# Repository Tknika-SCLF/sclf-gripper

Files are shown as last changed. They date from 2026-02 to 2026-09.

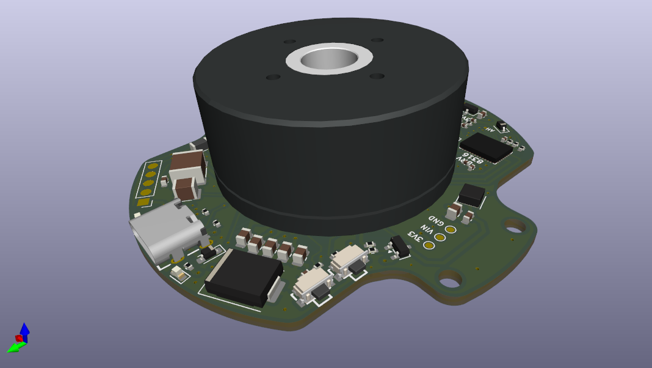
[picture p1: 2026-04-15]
images/Gripper_Motor1.png

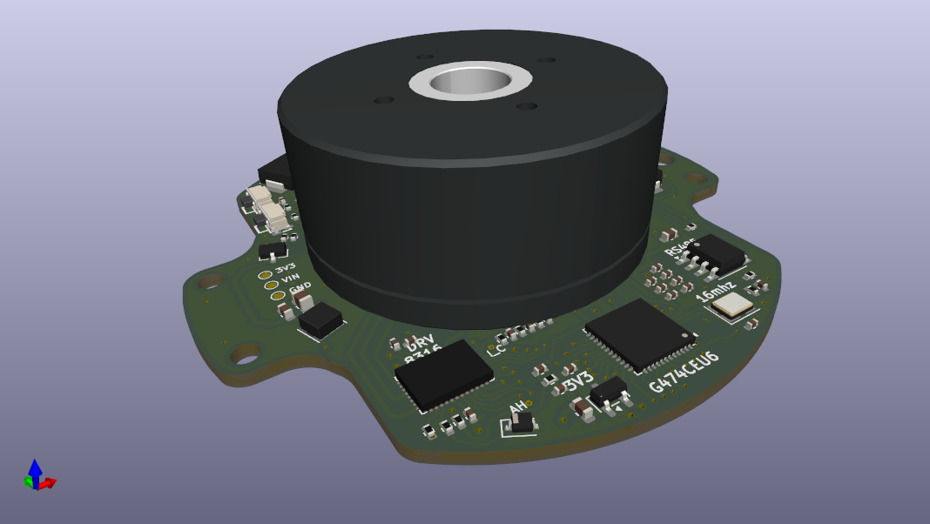
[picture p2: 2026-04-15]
images/Gripper_Motor4.png

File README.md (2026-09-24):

# SCLF Gripper — Firmwarea

[ Euskara ](README.md) | [ English ](README.en.md) | [ Español ](README.es.md)

> Tknikaren SCLF Gripper-erako motor kontrolagailuaren firmwarea.
> STM32G474CEU6 · SimpleFOC · PlatformIO · Antigravity IDE
> Lizentzia: CC BY-SA 4.0

---

> ⚠️ **GARRANTZITSUA:** Proiektu honekin lanean hasi aurretik, mesedez irakurri beti `TASKS.md` fitxategia. Bertan aurkituko duzu proiektuaren uneko egoera zehatza eta garatzaileen arteko hurrengo urratsak zeintzuk diren.

## Hasiera Azkarra

Ingurunea konfiguratuta baduzu dagoeneko:

```bash
# 1. Konpilatu
pio run

# 2. Flasheatu (ST-Link konektatuta)
pio run --target upload

# 3. Serie-monitorea (Gripper-aren USB-C PC-ra)
pio device monitor --baud 115200
```

---

## Ingurunearen Konfigurazioa Hutsetik

### 1. Urratsa — Antigravity Instalatu

Deskargatu eta instalatu Antigravity bere webgune ofizialetik. VSCode/Windsurf-en fork bat da eta modu berean funtzionatzen du.

---

### 2. Urratsa — C/C++ Tools Instalatu

> ⚠️ PlatformIO **ez dago Open VSX-en** (Antigravity-ren marketplace-a). Bi hedapenak eskuz instalatu behar dira `.vsix` fitxategietatik.

**2a.** Joan hona: https://github.com/microsoft/vscode-cpptools/releases/latest

Deskargatu zure sistema eragileari dagokion fitxategia:

| Sistema | Deskargatu beharreko fitxategia |
|---|---|
| Windows (64-bit) | `cpptools-windows-x64.vsix` |
| macOS (Apple Silicon) | `cpptools-macOS-arm64.vsix` |
| macOS (Intel) | `cpptools-macOS-x64.vsix` |
| Linux (64-bit) | `cpptools-linux-x64.vsix` |

**2b.** Antigravity-n: `Hedapenak / Extensions (Ctrl+Shift+X)` → `···` ikonoa (hiru puntu) → **Install from VSIX** → hautatu deskargatutako `.vsix` fitxategia.

---

### 3. Urratsa — PlatformIO Instalatu

**3a.** Joan hona: https://github.com/platformio/platformio-vscode-ide/releases/latest

Ireki azken bertsioaren **"Assets"** atala eta deskargatu fitxategia (adibidez: `platformio-ide-3.3.3.vsix`).

**3b.** Antigravity-n: `Hedapenak / Extensions (Ctrl+Shift+X)` → `···` → **Install from VSIX** → hautatu deskargatutako `.vsix` fitxategia.

**3c.** Berrabiarazi Antigravity. PlatformIOk bere mendekotasunak automatikoki instalatuko ditu lehenengo aldian (2-5 minutu har ditzake).

> ⚠️ **Ohar garrantzitsua:** PlatformIOren instalazioa Antigravity-n ez dago ofizialki onartuta. Konpilazio edo igoera (upload) arazoak badituzu, kontsultatu [Arazoen Konponbidea](#arazoen-konponbidea) atala dokumentu honen amaieran.

---

### 4. Urratsa — cortex-debug Instalatu (ST-Link-ekin debug egiteko)

> 💡 **Zer da Open VSX?** Kode irekiko luzapenen erregistro alternatiboa da (Eclipse Foundation-ek kudeatua). Antigravity-k eta VSCodium-ek ofizialki erabiltzen duten biltegia da, Microsoft-en murrizketak ekiditeko, eta segurua da.

**4a.** Joan hona: https://open-vsx.org/extension/marus25/cortex-debug

Eskuin aldean dagoen **"Version"** goitibeherako menuan, hautatu **"Pre-release"** jartzen EZ duen azken bertsio egonkorra (adibidez: `1.12.1`). Ondoren, sakatu azpian agertzen den **`DOWNLOAD`** botoi morean `.vsix` fitxategia eskuratzeko.

**4b.** Instalatu aurrekoak bezala (Install from VSIX).

**4c.** OpenOCD konfiguratzea:
> 💡 **Albiste ona:** Ez duzu ezer deskargatu edo instalatu behar! PlatformIO-k automatikoki deskargatzen du OpenOCD lehenengo aldiz proiektua konpilatzen edo plakan kargatzen duzunean. Bere kokapena hau izaten da Windows-en:
`C:\Users\ZURE_ERABILTZAILEA\.platformio\packages\tool-openocd\bin\openocd.exe`

*(Cortex-Debug-ek errorea ematen badu OpenOCD ez duela aurkitzen esanez, joan Antigravity-ren ezarpenetara eta ezarri ibilbide hori `cortex-debug.openocdPath` aukeran).*

---

### 5. Urratsa — Git Instalatu

Proiektua klonatzeko Git instalatuta izan behar duzu.

**5a.** Joan hona: https://git-scm.com/downloads

**5b.** Deskargatu eta instalatu zure sistema eragilearen bertsioa (lehenetsitako aukerak mantendu ditzakezu instalazioan).

---

### 6. Urratsa — Proiektua Ireki

```bash
# Klonatu edo kopiatu firmwarearen karpeta
# Ireki Antigravity erro karpetan (platformio.ini dagoen lekuan)
```

Antigravity-n: `File → Open Folder` → hautatu `SCLF_Gripper_firmware/` karpeta.

PlatformIOk automatikoki detektatuko du `platformio.ini` eta honako hauek deskargatuko ditu:
- Platform `ststm32`
- Framework `framework-arduinoststm32`
- Toolchain `toolchain-gccarmnoneeabi`
- `SimpleFOC` liburutegia

---

### 7. Urratsa — Lehenengo Konpilazioa

Antigravity-ren beheko barran, egin klik PlatformIOren ✓ (Build) ikonoan, edo terminaletik:

```bash
pio run
```

**Espero den emaitza:**
```
[SUCCESS] Took X.XX seconds
RAM:   [=         ]  X.X% (used XXXX bytes from 131072 bytes)
Flash: [=         ]  X.X% (used XXXXX bytes from 524288 bytes)
```

Konpilatzen ez badu → ikusi [Arazoen Konponbidea](#arazoen-konponbidea).

---

### 8. Urratsa — ST-Link Konektatu eta Flasheatu

Konektatu ST-Link SCLF Gripper-aren SWD atakara:

| Pin ST-Link | Pad Gripper | Seinalea |
|---|---|---|
| SWDIO | DIO | PA13 |
| SWCLK | CLK | PA14 |
| RST | RST | PG10 |
| GND | GND | — |
| 3.3V | 3V3 | (STM32 soilik elikatzen du, ez encoderra ez driverra) |

> ⚠️ **Elikadura:**
> - ST-Link-aren 3.3V pina **nahikoa da** STM32 flasheatzeko eta encoderra (MT6701) elikatzeko. Bera bakarrik probatu dezakezu 24V konektatu gabe.
> - **BAINA** DRV8316 driverrak eta motorrak **24V kanpokoa** behar dute. Test osoetarako (motorra mugitu), beti konektatu 24V elikadura.

Flasheatu:
```bash
pio run --target upload
```

**Espero den emaitza:** `[SUCCESS]` eta D4 LEDa (PC6) keinuka hasiko da.

#### Aurre-test gomendatua: LED Heartbeat

Test konplexuak egin aurretik, egiaztatu STM32 abiarazten dela:

1. Aldatu `build_src_filter` `platformio.ini`-n:
   ```ini
   build_src_filter = +<../examples/fase0_led_heartbeat>
   ```
2. Flasheatu `pio run --target upload` erabiliz.
3. D4 LEDak 5Hz-ra keinuka egin behar du (200ms). Keinurik ez bada → elikadura edo ST-Link kableatu arazoa.
4. Berreskuratu jatorrizko `build_src_filter` Fase 1.1-era itzuli nahi duzunean.

---

### 9. Urratsa — Encoderra Egiaztatu (Fase 1.1)

> ⚠️ **Baldintzak:** ST-Link-aren 3.3V konektatuta izatea nahikoa da encoderra elikatzeko. Ez da 24V behar fase honetarako.

`fase1_1_mt6701_test`-eko firmware-ak D4 LEDa diagnostiko bisual modura erabiltzen du (Serial gabe):

1. Egiaztatu `build_src_filter` horrela dagoela `platformio.ini`-n:
   ```ini
   build_src_filter = +<../examples/fase1_1_mt6701_test> +<encoder/>
   ```
2. Flasheatu: `pio run --target upload`
3. Begiratu D4 LEDa:

| LED portaera | Esanahia |
|---|---|
| 3 keinu azkar abiaraztean | `setup()` ondo amaituta |
| LED motela (700ms, ~0.7Hz) | Motorra lehen erdibiraketan (0°-180°) |
| LED azkarra (80ms, ~6Hz) | Motorra bigarren erdibiraketan (180°-360°) |
| **Motorra biratzean aldatzen da** ✅ | **MT6701 encoderrak funtzionatzen du!** |
| Beti azkar aldaketarik gabe | SPI-k 0xFFFF bueltatzen du → encoderrak elikadurarik ez |

✅ **LEDak motorra biratzean aldatzen badu, Fase 1.1 gaindituta dago.**

### 9b. Urratsa — Serial Monitor Egiaztatu (USB VCP)

> ✅ **EGOERA:** Ondo funtzionatzen du. Firmwareak `SystemClock_Config` bloke bat dauka `main.cpp`-n STM32G4-ren USB periferikorako behar den HSI48 osziladorea gaitzeko.

1. Konektatu USB-C kable bat Gripperraren eta PCaren artean.
2. Ireki PlatformIOren serie-monitorea (🔌 ikonoa beheko barran) edo sartu:
   ```bash
   pio device monitor --baud 115200
   ```
3. Testaren irteera ikusi beharko zenuke pantailan (Adib. `MT6701 Raw (con o sin 24V): X` edo biratzean aldatzen den balio bat).

---

### 10. Urratsa — Faseen Probak eta Adibideak (`examples/`)

Proiektu honen firmware garapena fase ezberdinetan banatuta dago (ikusi `TASKS.md`). Fase bakoitzean idatzitako kode-probak (test standalone-ak) **`examples/`** karpetaren barruan gordetzen dira.

Hardware berria muntatzen baduzu edo sentsore zehatz bat probatu nahi baduzu:
1. Sartu `examples/` karpetan eta aukeratu fasea (adib. `phase1_1_mt6701_test`, `phase1_2_drv_spi`, `phase1_4_rs485_ping`, `phase3_2_rs485_control` edo `phase3_3_ur_rs485`).
2. **Irakurri karpeta horretan dagoen `README.md` fitxategia** argibide zehatzak ikusteko.
   - **Oharra (Phase 3.3):** RS485 komunikazioa 115200 baud-etan doa UR robot eta URCap/URSim integrazio probarako.
3. Kopiatu bertako `main.cpp` fitxategia eta ordezkatu zure probako `src/main.cpp` fitxategiarekin (edo erabili dagokion ingurunea `platformio.ini`-n). 
4. Konpilatu eta igo (`pio run --target upload`).

---

### 11. Urratsa — IA Agentea Konfiguratu

Antigravity-n barneratuta dagoen IA laguntzailearekin lan egiteko:

1. Ireki agentearen txat-panela (IA ikonoa alboko barran).
2. Saio bakoitzaren hasieran, idatzi:

```
Irakurri testuinguru-fitxategi hauek lagundu aurretik:
- AGENT.md   (hardwarea, pinak, arkitektura)
- MEMORY.md  (uneko egoera, kalibratutako parametroak)
- TASKS.md   (orain lantzen ari naizen zeregina)
- RULES.md   (sortutako kodeak errespetatu behar dituen arauak)
```

3. Gero, deskribatu zein zeregin landu nahi duzun `TASKS.md`-tik.

---

## Proiektuaren Egitura

```
SCLF_Gripper_firmware/
│
├── src/
│   ├── main.cpp                    ← Sarrera puntua. 0 FASEA: smoke test
│   ├── config/
│   │   └── pins.h                  ← Pin GUZTIAK. Eskematikoarekin egiaztatuta.
│   ├── encoder/
│   │   ├── MT6701.h                ← Encoder-aren APIa (eskeletoa prest)
│   │   └── MT6701.cpp              ← 1.1 FASEAN inplementatu
│   ├── motor/
│   │   ├── DRV8316.h               ← Gate driver-aren APIa (eskeletoa prest)
│   │   └── DRV8316.cpp             ← 1.2 FASEAN inplementatu
│   ├── comms/
│   │   ├── RS485.h                 ← RS-485 APIa
│   │   └── RS485.cpp               ← RS-485 inplementazioa
│   └── faults/
│       ├── FaultManager.h          ← Akats kudeatzailearen APIa (eskeletoa prest)
│       └── FaultManager.cpp        ← 6 FASEAN inplementatu
│
├── lib/                            ← Bertako liburutegiak
├── test/                           ← PlatformIO Unity testak (8 FASEA)
│
├── examples/
│   ├── phase0_led_heartbeat/        ← 0 Fasea: LED keinua menpekotasunik gabe
│   ├── phase1_1_mt6701_test/        ← 1.1 Fasea: MT6701 encoder proba SPI bidez
│   ├── phase1_2_drv_spi/            ← 1.2 Fasea: DRV8316 SPI komunikazio proba
│   ├── phase1_3_open_loop_v_control/← 1.3 Fasea: Begizta irekiko tentsio kontrola
│   ├── phase1_4_rs485_ping/         ← 1.4 Fasea: RS-485 PING/PONG oinarrizkoa
│   ├── phase2_1_foc_open_loop/      ← 2.1 Fasea: FOC begizta irekiko kontrola
│   ├── phase2_2_foc_closed_loop/    ← 2.2 Fasea: FOC begizta itxia
│   ├── phase3_1_rs485_basic/        ← 3.1 Fasea: RS-485 oinarrizko protokoloa
│   ├── phase3_2_rs485_control/      ← 3.2 Fasea: RS-485 kontrol komando osoak
│   └── phase3_3_ur_rs485/           ← 3.3 Fasea: UR Robot / URCap RS-485 integrazioa
│
├── .vscode/
│   ├── settings.json               ← IDE konfigurazioa (IntelliSense, formatua)
│   ├── extensions.json             ← Gomendatutako hedapenak
│   └── launch.json                 ← Debug ST-Link cortex-debug-ekin
│
├── platformio.ini                  ← Build eta upload konfigurazioa
├── .clang-format                   ← Kode estiloa (gordetzean aplikatzen da)
├── .gitignore
│
├── AGENT.md    ← 📋 IA agentearentzako testuingurua
├── MEMORY.md   ← 🧠 Proiektuaren egoera iraunkorra
├── TASKS.md    ← ✅ Backlog osoa faseka
├── RULES.md    ← 📏 Proiektuaren arauak
└── SRS.md      ← 📄 Eskakizunen zehaztapena
```

### Arkitektura Modularraren Azalpena

Proiektu hau berezibila eta antolatua izateko garatu da:
* **`main.cpp` ("Zuzendaria"):** FOC kontrol-begizta eta hasierako konfigurazioa soilik ditu. Ez da kode nahaspilatuz betetzen.
* **`.cpp` espezifikoak ("Musikariak"):** Txip bakoitzak bere artxibo dedikatua dauka bere funtzio jakingarriagoetarako (adibidez `MT6701.cpp` posizioa zuzenean irakurtzeko erroreak kontrolatuz, edo `DRV8316.cpp` tenperatura edo zirkuitulabur kasuez informatzeko).
* **Modu honetan:** `main.cpp`-ak oinarrizko aginduak ematen ditu, eta modulu bakoitzak badaki bere tresna zehazki nola erabili, etorkizuneko hardware aldaketak izugarri erraztuz.

### Hardware Segurtasuna eta Garapena (⚠️ OSO GARRANTZITSUA)

Antigravity barruan proiektu hau garatzean, [Arau Zorrotzak (RULES.md)](RULES.md) ezarrita daude:
1. **Debekatuta dago Blokeatzea:** Inoiz ez erabili `delay()`, `HAL_Delay` edo `while()` begizta infiniturik FOC exekuzioan. SimpleFOC-ek mikroren %100 erabiltzea eskatzen du korrontea denbora errealean kalkulatzeko. Mikroa "lotaratzeak" motorra edo driverra segundo batean erretzea ekar dezake.
2. **`foc-hardware-setup` Tresna (Skill):** Kodea garatzen hasi aurretik, gure IA laguntzaileak badu tresna espezifiko bat KiCad-eko eskema elektrikoak zuzenean irakurtzeko (`.kicad_sch`) eta `pins.h` fitxategi ezin hobea sortzeko, inolako giza-akatsik gabe. Zure laguna da, erabili proiektuaren azken pinen zehaztapenak egiaztatzeko!
3. **Cortex-Debug Magia:** ST-Link v2 klonarekin edo jatorrizkoarekin, Plaka zuzenean kontrolatu eta pausatu daiteke. Programan aldagairen batek zergatik hartzen duen balio jakin bat deskubritu nahi bada, jarri Breakpoint (eten-puntu) bat Antigravity-n, eta kodea zuzen-zuzenean pausatuko da STM32-an!

---

## PlatformIO Komando Erabilienak

```bash
pio run                          # Konpilatu
pio run --target upload          # Konpilatu eta flasheatu (ST-Link)
pio run --target upload_dfu      # USB DFU bidez flasheatu (BOOT + RST)
pio device monitor               # Serie-monitorea (USB VCP, 115200 baud)
pio test                         # Test unitarioak exekutatu
pio run --target clean           # Konpilazio-artefaktuak garbitu
pio lib install "Simple FOC"     # Eskuz instalatu liburutegia
pio pkg update                   # Plataforma eta liburutegiak eguneratu
```

---

## DFU Bootloader (Flasheatu ST-Link gabe)

ST-Link erabilgarririk ez baduzu, USB DFU bidez flashea dezakezu:

1. Mantendu sakatuta **BOOT** (PB8) botoia.
2. Sakatu eta askatu **RESET** (PG10) botoia.
3. Askatu **BOOT**.
4. Gripperra DFU gailu gisa agertuko da PCan.
5. Aldatu `upload_protocol = dfu` fitxategian `platformio.ini`.
6. Exekutatu `pio run --target upload`.

> 💡 **Oharra ST-Link gabe DFU erabiltzearen inguruan (PA9 pina):**
> Ohiko STM32etan (F1/F4), USB kablea konektatuta dagoela nabaritzeko (VBUS sensing) `PA9` pina erabiltzen da. Gure diseinuan, ordea, `PA9` pina motorraren B fasera (DRV8316) konektatuta dago (`PIN_BH`). Baina ez larritu! **STM32G4 familiak VBUS sentsorea hardware bidez desgaituta dauka** bere Bootloader nagusian (AN2606). Hori dela eta, DFU moduak primeran funtzionatuko du soilik `PA11` eta `PA12` datu-pinak erabiliz, hardware aldaketen beharrik gabe.
> 
> **⚠️ KONTUZ Arazketa (Debugging) egiteko orduan:**
> Kontuan izan USB DFU metodoa "itsu-itsuan pentsatua" dela: kodearen irudia (`.bin`) mikroaren memorian kargatzeko **soilik** balio du. Garapen-fasean zaudenean eta SimpleFOC motorraren ezusteko portaera bat ikertu behar duzunean, **ezinbestekoa da ST-Link (edo SWD) bat erabiltzea**. ST-Link batek zuzenean ARM Cortex muinera konektatzen zaitu `PA13/PA14` bidez, eta aukera ematen dizu kodea pausatzeko (Breakpoints), aldagaien balioak denbora errealean irakurtzeko eta exekuzioa lerroz lerro aztertzeko VS Code-n. USB-ak ezin du horrelakorik egin.

---

## Arazoen Konponbidea

### PlatformIOk ez du konpilatzen / toolchain errorea
```bash
# STM32 plataforma berrinstalatu
pio platform install ststm32

# Garbitu eta berriro konpilatu
pio run --target clean && pio run
```

### ST-Link-ek ez du plaka detektatzen
- Egiaztatu ST-Link-eko GNDa gripperreko GND-ra konektatuta dagoela.
- Egiaztatu plakak elikadura duela (PWR LEDa piztuta).
- Probatu `openocd -f interface/stlink.cfg -f target/stm32g4x.cfg` terminalean.
- OpenOCD-k huts egiten badu: eguneratu ST-Link firmwarea STM32CubeProgrammer-etik.

### USB VCP ez da agertzen PCan
- Instalatu STM32 VCP kontrolatzailea (driverra): https://www.st.com/en/development-tools/stsw-stm32102.html (Windows soilik)
- Linux/macOS sistemetan ez dago kontrolatzailerik behar. Egiaztatu `ls /dev/ttyACM*` erabiliz.

### LEDak ez du keinurik egiten flasheatu ondoren
- **Ziurtatu erlojuaren konfigurazioa duzula:** STM32duino framework-ak `-DUSBCON` flag-ekin (berez aktibatuta proiektu honetan) USB CDC possesses `setup()` baino **lehenago** hasieratzen du. `main.cpp`-ren amaieran HSI48 aktibatzen duen `SystemClock_Config(void)` funtzioa falta bada, firmwarea blokeatu egiten da.
- Probatu `examples/fase0_led_heartbeat` (LED soilik, menpekotasunik gabe). Horrek ere funtzionatzen ez badu → elikadura edo kableatu arazoa.

### Serial Monitoreak ez du daturik erakusten (pantaila hutsik)
- Ziurtatu COM ataka zuzenean konektatzen zarela. ST-Link-ek COM bereizi bat sortzen du: COM hori beti isilik egongo da. Bilatu "STM32 Virtual COM Port" Gailu Kudeatzailean.
- Flasheatu berri baduzu, Windows-ek segundo bat behar izan dezake USB berria ezagutzeko. PlatformIO-k ataka zaharrean monitorea ireki badu, "zintzilik" geratuko da. Kantzelatu terminalean `Ctrl+C` erabiliz eta exekutatu `pio device monitor` berriro.

### IntelliSense-k ez du `Arduino.h` edo STM32 header-ak aurkitzen
- Itxaron PlatformIOk lehenengo konpilazioa amaitu arte (includes indizea sortzen du).
- Arazoak jarraitzen badu: `Ctrl+Shift+P` → "C/C++: Reset IntelliSense Database".

### Antigravity / PlatformIO ez da plakarekin komunikatzen
- Hau komunitatean dokumentatuta dagoen arazo ezaguna da. PlatformIO Antigravity-n
  ez dago ofizialki onartuta. Konpilazioak funtzionatzen badu baina igotzeak (upload) huts egiten badu,
  saiatu `pio run --target upload` exekutatzen **barne terminaletik**, PlatformIOko
  UI botoiaren ordez.

### PlatformIOk "ms-vscode.cpptools" eskatzen du etengabe (Menpekotasunen Kirurgia)
PlatformIOk batzuetan Microsoft-en hedapena instalatzea exijitzen du, nahiz eta eskuz instalatuta izan. Arazoa konpontzeko:
1. Itxi Antigravity erabat.
2. Ireki fitxategi-esploratzailea eta joan hona: `%USERPROFILE%\.antigravity\extensions\` (Windows) edo `~/.antigravity/extensions/` (Linux/macOS).
3. Sartu `platformio.platformio-ide-...` izeneko karpetan.
4. Ireki `package.json` fitxategia testu-editore batekin.
5. Bilatu `"extensionDependencies": ["ms-vscode.cpptools"]` lerroa.
6. Utzi hutsik horrela: `"extensionDependencies": []`
7. Gorde fitxategia eta berrabiarazi Antigravity.

---

## Erreferentziazko Hardwarea

| Osagaia | Zatia | Datasheet-a |
|---|---|---|
| MCU | STM32G474CEU6 | [ST.com](https://www.st.com/resource/en/reference_manual/rm0440-stm32g4-series-advanced-armbased-32bit-mcus-stmicroelectronics.pdf) |
| Gate Driver | DRV8316CRRGFR | [TI.com](https://www.ti.com/lit/ds/symlink/drv8316.pdf) |
| Encoder | MT6701QT | [Magntek](https://www.magntek.com.cn/upload/MT6701_Rev.1.8.pdf) |
| RS-485 | MAX3485 | [Analog](https://www.analog.com/media/en/technical-documentation/data-sheets/MAX3483-MAX3491.pdf) |
| SimpleFOC | v2.x | [docs.simplefoc.com](https://docs.simplefoc.com) |

---

*Tknikak diseinatua — Licensed under CC BY-SA 4.0*

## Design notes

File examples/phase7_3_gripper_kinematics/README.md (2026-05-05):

# 7.3 Fasea - Pintzaren Zinematika (Gripper Kinematics)

Karpeta honetan 7.3 Fasearen (`phase7_3_gripper_kinematics`) kode egiaztatua dago. Fase honen helburua motorraren angelua (radianetan) pintzaren hatzen irekidurarekin (milimetrotan) lotzea da.

### Zer egiten du?

`GripperKinematics` klase parametrizatu bat sortu da, non lead-screw mekanismoaren zinematika bihurketak egiten diren:
- **Angelu → mm**: Motorraren angelua hatzen irekidurara bihurtu
- **mm → Angelu**: Nahi den irekidura motor angelura bihurtu
- **Portzentaje (%) → Angelu**: 0% = irekita, 100% = itxita
- **Clamping**: Muga fisikoetatik kanpoko balioak automatikoki mugatzen dira

### Konfigurazio Aurredefinituak

| Preseta | Stroke | Indar Max. |
|---|---|---|
| `ROBOTIQ_2F85` | 85 mm | 235 N |
| `ROBOTIQ_2F140` | 140 mm | 249 N |

### Nola probatu

1. Konpilatu eta kargatu firmwarea ingurune espezifikoa erabiliz:
   ```bash
   pio run -e test_gripper_kinematics --target upload
   ```
2. Ireki Serie Monitorea (115200 baud).
3. Hasieran zinematikako proba automatiko bat exekutatzen da.
4. Serial-etik mm balio bat bidali eta bihurketak ikusiko dituzu.

### Nola egokitu zure pintzara

Editatu `GripperKinematics.h` fitxategian `GripperPresets` namespace-a, edo sortu zure `GripperConfig`:
```cpp
GripperConfig nireConfig = {
    .stroke_mm      = 60.0f,    // Zure irekidura (mm)
    .gear_ratio     = 3.5f,     // Zure engranaje erlazioa
    .lead_mm        = 2.0f,     // Zure usilloaren urratsa
    .min_angle_rad  = 0.0f,
    .max_angle_rad  = 0.0f,     // Auto-kalkulatua
    .max_force_N    = 100.0f,
};
gripper.begin(nireConfig);
```

---

# Fase 7.3 - Cinemática de la Pinza (Gripper Kinematics) [ES]

En esta carpeta se encuentra el código verificado de la Fase 7.3 (`phase7_3_gripper_kinematics`). El objetivo de esta fase es relacionar el ángulo del motor (en radianes) con la apertura de los dedos de la pinza (en milímetros).

### ¿Qué hace?

Se ha creado una clase parametrizada `GripperKinematics` donde se realizan las conversiones cinemáticas del mecanismo lead-screw:
- **Ángulo → mm**: Convierte el ángulo del motor a la apertura de los dedos
- **mm → Ángulo**: Convierte la apertura deseada al ángulo del motor
- **Porcentaje (%) → Ángulo**: 0% = abierto, 100% = cerrado
- **Clamping**: Los valores fuera de los límites físicos se limitan automáticamente

### Configuraciones Predefinidas

| Preset | Stroke | Fuerza Máx. |
|---|---|---|
| `ROBOTIQ_2F85` | 85 mm | 235 N |
| `ROBOTIQ_2F140` | 140 mm | 249 N |

### Cómo Probarlo

1. Compila y carga el código usando el entorno específico:
   ```bash
   pio run -e test_gripper_kinematics --target upload
   ```
2. Abre el Monitor Serie (115200 baudios).
3. Al inicio se ejecuta una prueba cinemática automática.
4. Envía un valor en mm por el puerto serie y verás las conversiones.

### Cómo adaptarlo a tu pinza

Edita el namespace `GripperPresets` en el archivo `GripperKinematics.h`, o crea tu propia `GripperConfig`:
```cpp
GripperConfig miConfig = {
    .stroke_mm      = 60.0f,    // Tu apertura (mm)
    .gear_ratio     = 3.5f,     // Tu relación de engranajes
    .lead_mm        = 2.0f,     // Tu paso de husillo
    .min_angle_rad  = 0.0f,
    .max_angle_rad  = 0.0f,     // Auto-calculado
    .max_force_N    = 100.0f,
};
gripper.begin(miConfig);
```

---

# Phase 7.3 - Gripper Kinematics [EN]

This folder contains the verified code for Phase 7.3 (`phase7_3_gripper_kinematics`). The goal of this phase is to link the motor angle (in radians) with the gripper finger opening (in millimeters).

### What does it do?

A parameterized class `GripperKinematics` has been created to perform the kinematic conversions of the lead-screw mechanism:
- **Angle → mm**: Convert motor angle to finger opening
- **mm → Angle**: Convert desired opening to motor angle
- **Percentage (%) → Angle**: 0% = open, 100% = closed
- **Clamping**: Values outside physical limits are automatically constrained

### Predefined Configurations

| Preset | Stroke | Max. Force |
|---|---|---|
| `ROBOTIQ_2F85` | 85 mm | 235 N |
| `ROBOTIQ_2F140` | 140 mm | 249 N |

### How to Test

1. Compile and upload the firmware using the specific environment:
   ```bash
   pio run -e test_gripper_kinematics --target upload
   ```
2. Open the Serial Monitor (115200 baud).
3. An automatic kinematics test is executed at startup.
4. Send a mm value through the serial port and you will see the conversions.

### How to adapt it to your gripper

Edit the `GripperPresets` namespace in the `GripperKinematics.h` file, or create your own `GripperConfig`:
```cpp
GripperConfig myConfig = {
    .stroke_mm      = 60.0f,    // Your opening (mm)
    .gear_ratio     = 3.5f,     // Your gear ratio
    .lead_mm        = 2.0f,     // Your lead-screw pitch
    .min_angle_rad  = 0.0f,
    .max_angle_rad  = 0.0f,     // Auto-calculated
    .max_force_N    = 100.0f,
};
gripper.begin(myConfig);
```

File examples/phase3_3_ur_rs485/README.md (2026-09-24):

# 3.3 Fasea - UR Robot / URCap RS-485 Integrazio Probak [EU]

Karpeta honetan 3.3 Fasearen (`phase3_3_ur_rs485`) inplementazioa eta dokumentazioa dago. Fase honen helburua gripperra UR (Universal Robots) robot baten kontrolagailura konektatzea eta RS-485 bus bidezko komunikazioa eta kontrola balioztatzea da (URCap eta URSim bidez).

## Kableatu eta Konexio Diagrama

Konektatu robotaren RS-485 interfazea gripperraren **J3** konektorera honela:

| Gripper J3 Pin | Seinalea | UR Robot / RS-485 Egokitzailea |
|:---:|:---:|:---:|
| **Pin 7** | RS485+ (A) | RXD/TXD+ (A) |
| **Pin 8** | RS485- (B) | RXD/TXD- (B) |
| **Pin 1 & 2** | GND | GND |

> [!IMPORTANT]
> Seinaleak zuzen doazela ziurtatu eta kable biek lur berbera (GND) erabili behar dute zarata diferentziala saihesteko.

## Komandoen Zerrenda eta Protokoloa

Komunikazioak **115200 baudios**-eko abiadura lehenesten du, UR robotetako eta URCap komunikazioetan estandarra baita. Formatua: `<device_id>:<cmd>:<value>\n` da (adibidez gailu ID = `1`).

| Komandoa | Deskribapena | Ekintza | Adibidea | Erantzuna |
|:---:|:---:|:---:|:---:|:---:|
| `PING` | Bus detekzioa | Komunikazioa probatu | `1:PING:0\n` | `1:PONG:0.0000\n` |
| `EN` | Habilitar | Gripperra gaitu | `1:EN:0\n` | `1:ACK_EN:1.0000\n` |
| `DIS` | Disable | Gripperra desgaitu | `1:DIS:0\n` | `1:ACK_DIS:0.0000\n` |
| `P` | Position (0-85) | Posizioa ezarri (mm-tan) | `1:P:42.5\n` | `1:ACK_P:42.5000\n` |
| `V` | Speed (0-100) | Abiadura ehunekoa ezarri | `1:V:80\n` | `1:ACK_V:80.0000\n` |
| `T` | Force (0-100) | Indar ehunekoa ezarri | `1:T:50\n` | `1:ACK_T:50.0000\n` |
| `?A` | Get Angle | Uneko posizioa lortu (mm) | `1:?A:0\n` | `1:A:<posizioa>\n` |
| `?S` | Get Status | Egoera bitak lortu (0x01: Galduta/Aktibatuta, 0x02: Mugimenduan, 0x04: Akatsa) | `1:?S:0\n` | `1:S:<egoera_bita>\n` |

### LED eta Simulatutako Mugimendua
Fase honetan komunikazio protokoloa eta URCap-arekiko elkarreragina segurtasunez balioztatzen dira. Potentzia irteerak (PWM eta DRV CS) desgaituta daude hardware segurtasunagatik, eta mugimendua software bidez simulatzen da:
- **LED Keinua:** Desgaituta dagoenean 1000 ms, gaituta dagoenean 500 ms, eta mugimenduan dagoenean 100 ms (keinu azkarra).

## Nola Probatu

1. Ziurtatu `platformio.ini`-n `test_ur_rs485` ingurunea aukeratuta dagoela.
2. Konpilatu eta igo firmwarea gripper-era:
   ```bash
   pio run -e test_ur_rs485 --target upload
   ```
3. Exekutatu URSim eta URCap-a (edo RS-485 egokitzaile bat PC-an **115200 baudios**-era).
4. Bidali komandoak eta ikusi ACK erantzunak.

---

# Fase 3.3 - Pruebas de Integración RS-485 con Robot UR / URCap [ES]

En esta carpeta se encuentra la implementación y documentación de la Fase 3.3 (`phase3_3_ur_rs485`). El objetivo de esta fase es conectar el gripper al controlador de un robot UR (Universal Robots) y validar el bus RS-485 y el protocolo de comandos desde URCap y URSim.

## Diagrama de Cableado y Conexión

Conectar la interfaz RS-485 del robot al conector **J3** del gripper:

| Pin J3 Gripper | Señal | UR Robot / Adaptador RS-485 |
|:---:|:---:|:---:|
| **Pin 7** | RS485+ (A) | RXD/TXD+ (A) |
| **Pin 8** | RS485- (B) | RXD/TXD- (B) |
| **Pin 1 & 2** | GND | GND |

> [!IMPORTANT]
> Verificar la polaridad de las líneas A/B y asegurar la referencia común de masa (GND) para evitar ruido diferencial.

## Lista de Comandos y Protocolo

La comunicación opera a **115200 baudios**, que es el estándar en Universal Robots y daemons URCap. El formato es `<device_id>:<cmd>:<value>\n` (por defecto Device ID = `1`).

| Comando | Descripción | Acción | Ejemplo | Respuesta |
|:---:|:---:|:---:|:---:|:---:|
| `PING` | Detección de bus | Probar comunicación | `1:PING:0\n` | `1:PONG:0.0000\n` |
| `EN` | Habilitar | Habilitar gripper | `1:EN:0\n` | `1:ACK_EN:1.0000\n` |
| `DIS` | Deshabilitar | Deshabilitar gripper | `1:DIS:0\n` | `1:ACK_DIS:0.0000\n` |
| `P` | Posición (0-85) | Ajustar apertura (mm) | `1:P:42.5\n` | `1:ACK_P:42.5000\n` |
| `V` | Velocidad (0-100) | Ajustar % de velocidad | `1:V:80\n` | `1:ACK_V:80.0000\n` |
| `T` | Fuerza (0-100) | Ajustar % de par/fuerza | `1:T:50\n` | `1:ACK_T:50.0000\n` |
| `?A` | Consultar posición | Leer posición actual (mm) | `1:?A:0\n` | `1:A:<posicion>\n` |
| `?S` | Consultar estado | Leer byte de estado (0x01: Enabled, 0x02: Moving, 0x04: Fault) | `1:?S:0\n` | `1:S:<status_byte>\n` |

### Comportamiento del LED y Simulación
En esta fase se valida la robustez de las tramas de comunicación de forma aislada. Por seguridad de hardware, las salidas de los transistores PWM y el chip select del DRV8316 permanecen inhibidos. La cinemática se emula por software:
- **LED de estado:** 1000 ms cuando está deshabilitado (`DIS`), 500 ms cuando está habilitado (`EN`) y 100 ms (parpadeo rápido) mientras dura la traslación hacia la posición objetivo. Al llegar al objetivo, `state.moving` se apaga y el LED vuelve a 500 ms.

## Cómo Probarlo

1. Asegurarse de seleccionar el entorno `test_ur_rs485` en `platformio.ini`.
2. Compilar y cargar el firmware al gripper:
   ```bash
   pio run -e test_ur_rs485 --target upload
   ```
3. Ejecutar URSim con el URCap desplegado (o conectar mediante adaptador USB-RS485 a 115200 baudios).
4. Probar las funciones de ping, activación (`EN`), fijación de velocidad (`V`), fijación de posición (`P`) y consulta de estado (`?S`).

---

# Phase 3.3 - UR Robot / URCap RS-485 Integration Tests [EN]

This folder contains the implementation and documentation for Phase 3.3 (`phase3_3_ur_rs485`). The goal of this phase is to connect the gripper to a Universal Robots (UR) robot controller and validate RS-485 bus communications and command protocols using URCap and URSim.

## Wiring and Connection Diagram

Connect the robot's RS-485 interface to the gripper's **J3** connector:

| Gripper J3 Pin | Signal | UR Robot / RS-485 Adapter |
|:---:|:---:|:---:|
| **Pin 7** | RS485+ (A) | RXD/TXD+ (A) |
| **Pin 8** | RS485- (B) | RXD/TXD- (B) |
| **Pin 1 & 2** | GND | GND |

> [!IMPORTANT]
> Verify correct polarity on lines A and B and ensure a common ground reference (GND) to avoid differential noise.

## Command List and Protocol

Communication is set to **115200 baud**, the standard baud rate for Universal Robots tool communication and URCap daemons. Format: `<device_id>:<cmd>:<value>\n` (default Device ID = `1`).

| Command | Description | Action | Example | Response |
|:---:|:---:|:---:|:---:|:---:|
| `PING` | Bus scan | Verify communication | `1:PING:0\n` | `1:PONG:0.0000\n` |
| `EN` | Enable | Enable gripper | `1:EN:0\n` | `1:ACK_EN:1.0000\n` |
| `DIS` | Disable | Disable gripper | `1:DIS:0\n` | `1:ACK_DIS:0.0000\n` |
| `P` | Position (0-85) | Set position (mm) | `1:P:42.5\n` | `1:ACK_P:42.5000\n` |
| `V` | Speed (0-100) | Set speed percentage | `1:V:80\n` | `1:ACK_V:80.0000\n` |
| `T` | Force (0-100) | Set torque/force percentage | `1:T:50\n` | `1:ACK_T:50.0000\n` |
| `?A` | Get Angle | Read current position (mm) | `1:?A:0\n` | `1:A:<position>\n` |
| `?S` | Get Status | Read status byte (0x01: Enabled, 0x02: Moving, 0x04: Fault) | `1:?S:0\n` | `1:S:<status_byte>\n` |

### LED Behavior and Simulation
In this phase, communications and URCap protocol handling are validated in isolation. For hardware safety, the PWM outputs and DRV8316 chip select are held disabled. Motion is simulated via software:
- **Status LED:** 1000 ms blink when disabled (`DIS`), 500 ms when enabled and idle (`EN`), and 100 ms (fast blink) while actively moving towards the target position. Once the target position is reached, `state.moving` returns to false and the blink returns to 500 ms.

## How to Test

1. Ensure the `test_ur_rs485` environment is configured in `platformio.ini`.
2. Build and upload firmware to the gripper:
   ```bash
   pio run -e test_ur_rs485 --target upload
   ```
3. Run URSim with the URCap deployed (or use a USB-RS485 adapter at 115200 baud).
4. Send commands and verify immediate ACK replies and state transitions.

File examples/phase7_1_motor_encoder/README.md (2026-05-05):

# 7.1 Fasea: Motor-Encoder Lerrokatzea

Adibide honek motorraren (GM3506, 11 pare polo) eta MT6701 encoder magnetikoaren arteko lerrokatze elektrikoa egiten du SimpleFOC liburutegia erabiliz, eta lazo itxiko kontrola balioztatzen du (Torque, Abiadura eta Posizio moduak).

## Helburuak
- `motor.initFOC()` exekutatzea `zero_electric_angle` eta `sensor_direction` fisikoki determinatzeko.
- **Torque**, **Abiadura** eta **Posizio** kontrola lazo itxian balioztatzea.
- Kalibrazio parametroak Flash-ean iraunaraztea.

## Hardware Ezaugarriak
- **Motorra**: GM3506 gimbal motorra (11 pare polo, 24N22P)
- **Enkoderra**: MT6701 (bit-bang SPI, PA5/PA6/PA4 pinen bidez)
- **Dribera**: DRV8316 (6-PWM, SPI dedicatua PB3/PB4/PB5)
- **MCU**: STM32G474CEU6

## Argibideak: Lehen Erabileran

### 1. Kargatu eta Abiatu
```bash
pio run -e test_foc_advanced --target upload
```

### 2. STALL desaktibatu tuning-erako (lehenengo aldiz)
```
X
```
Irteera: `[DIAG] STALL detector: DISABLED (tuning mode)`

### 3. Kalibratu fisikoki (Flash hutsik badago)
Arrazoiarazten bada `[FLASH] Flash data has UNKNOWN direction`, motorrak bere kabuz lerrokatuko da (`initFOC()`).
Irteerak honelako itxura izango du:
```
[MAIN] FOC Initialized successfully.
[CAL] zero_electric_angle = 1.1098
[CAL] sensor_direction    = -1
```
> ⚠️ El motor se bloqueará brevemente durante la alineación. **Asegúrese de que puede girar libremente.**

### 4. Torque modua probatu (lazo itxiko egiaztapena)
```
M C 0      ← Torque modua
M 2        ← 2V zuzenean q-ardatzean
T1         ← Telemetria aktibatu
```
Emaitza zuzena: `V: ~35 rad/s` eta `A:` hazten (motorra biratzen).

### 5. Abiadura modua probatu
```
M C 1      ← Abiadura modua
M V P 2    ← P handiagoa (P=0.3 ez da nahikoa hasierako frikaziorako)
M V I 0    ← I=0 hasierako tuning-erako (windupa saihesteko)
M 1        ← 1 rad/s helburua
T1
```
Emaitza zuzena: `V: ~1.00` egonkortu.

### 6. Posizio modua probatu
```
M C 2           ← Posizio modua (angle mode)
M 800           ← Uneko shaft_angle-tik gertu dagoen balioa
M 820           ← Beste posizio bat
```
> **Oharra**: `shaft_angle` metatzen da rotazio guztietan. `M 3.14` erabili beharrean, uneko `A:` baliora gertu dauden helburuak erabili.

### 7. Kalibrazioa gorde
```
S
```
`[FLASH] Calibration saved! Press RESET to reload cleanly.` mezua ikusi ondoren, **RESET fisikoa sakatu**.

### 8. Flash-etik kargatu egiaztatu
Berrabiaraztean, ez da kalibrazio fisikorik egingo:
```
[FLASH] Valid calibration found. Applying...
[MAIN] FOC Initialized successfully.
[CAL] zero_electric_angle = 1.1098
[CAL] sensor_direction    = -1
```

## Komandoak

| Komandoa | Deskribapena |
|---|---|
| `M C 0` | Torque modua |
| `M C 1` | Abiadura lazo itxia |
| `M C 2` | Posizio modua |
| `M <balio>` | Helburua ezarri (modua arabera: torque V, abiadura rad/s, posizio rad) |
| `M V P <balio>` | PID abiadura P ezarri |
| `M V I <balio>` | PID abiadura I ezarri |
| `O <balio>` | Lazo irekiko abiadura (testetzeko) |
| `T1` / `T0` | Telemetria piztu/itzali |
| `X` | STALL detektagailua aktibatu/desaktibatu |
| `S` | Kalibrazioa Flash-ean gorde |
| `R` | Flash berrezarri (hurrengo abiaraztean kalibratu) |
| `C` | Kalibrazio fisikoa behartu |
| `D` | DRV8316 erregistroen diagnostikoa |
| `F` | STALL faila garbitu eta motorra berraktibatu |
| `A <balio>` | `zero_electric_angle` eskuz ezarri |
| `Z` | ZEA diagnostikoa (lazo irekian) |

## Egiaztapena
- ✅ `initFOC()` arrakastaz exekutatu (`zero_electric_angle` eta `sensor_direction` lortuz)
- ✅ Torque moduan `V: ~35 rad/s` lortu `Uq=2V`-rekin
- ✅ Abiadura moduan `V: ~1.00 rad/s` egonkortu `P=2, I=0`-rekin
- ✅ Posizio moduan helburura mugitu eta mantendu
- ✅ Flash-etik kalibrazioa kargatu eta kalibrazio fisikorik gabe funtzionatu

## Arazoen Konponbidea (Troubleshooting)
- **Motorrak dar-dar egiten du baina ez du biratzen Torque/Abiadura moduan**:
  - *Zergatia*: `zero_electric_angle` okerra, kalibrazioan errotorea aske ez zegoelako.
  - *Konponbidea*: `R` komandoa bidali Flash-a garbitzeko, RESET sakatu eta utzi motorrari oztoporik gabe kalibratzen.
- **Motorrak txistu egiten du eta ez da mugitzen Abiadura moduan**:
  - *Zergatia*: PID-aren `P` irabazia baxuegia da marruskadura gainditzeko.
  - *Konponbidea*: Igo `P` pixkanaka (`M V P 2`, `M V P 3`) mugimendu leuna lortu arte.
- **Bibrazio bortitza Abiadura moduan PID-a doitzean**:
  - *Zergatia*: Termino integrala (I) errorea metatzen ari da (windup).
  - *Konponbidea*: Ezarri integrala zerora (`M V I 0`) P egonkorra aurkitu arte.
- **Posizio modura aldatzean motorrak bira zoroak egiten ditu**:
  - *Zergatia*: `shaft_angle`-k aurreko probetako (adibidez, torque modua) bira guztiak metatzen ditu.
  - *Konponbidea*: Irakurri uneko angelua telemetriarekin (`T1`) eta bidali hortik gertu dagoen helburu bat, edo berrabiarazi plaka.
- **STALL errorea agertzen da eta motorra gelditzen da**:
  - *Zergatia*: STALL detektagailuak motorra babesten du blokeatuta badago eta tentsio altua jasotzen badu. Tuning garaian, irabazi baxuekin gerta daiteke.
  - *Konponbidea*: Desaktibatu STALL behin-behinean `X` komandoa erabiliz.

## Konpondu diren Bug Kritikoak

### 1. TIM1_BKIN Gateazka (PA6)
`driver.init()` exekutatzean, TIM1 periferikoak PA6 pina `BKIN` funtzio alternatiboetara konfiguratzen zuen, MT6701 enkoderra hautsiz.
**Konponketa**: `driver.init()` ostean `pinMode()` erabiliz PA6 GPIO modura berriz ezarri.

### 2. SPI Bektorioa Gatazka
`SPI` objektu globalak PA5/PA6 erabil ditzake, enkoderre-ak erabiltzen dituen pinekin talka eginez.
**Konponketa**: DRV8316-rako `SPIClass` instantzia dedikatua (`_spi_drv`) sortu PB3/PB4/PB5 pinekin.

### 3. Flash Kalibrazio Balioztatzea
`resetToDefaults()` funtzioak `sensor_direction=CW` ezartzen zuen, kalibrazio faltsu bat sortuz.
**Konponketa**: Default-ak `sensor_direction=UNKNOWN (0)` ezartzeko aldatu, berriro kalibratzera behartuz.

### 4. Flash Idazketa Blokeoa
`HAL_FLASH_Program()` ~30ms blokeatzen du, FOC begizta desinkronizatuz.
**Konponketa**: `S` komandoa exekutatu aurretik motorra desaktibatu eta ostean berriro aktibatu.

### 5. Zero Elekrikoa Okerra (zero_electric_angle)
Kalibrazio saio batean `ZEA=4.9195, dir=1` lortu zen, baina closed-loop torquea ez zen sortzen. Arrazoiak: motor ez-askea lerrokatzean, edo alineazio tentsio baxuegia (`voltage_sensor_align`).
**Konponketa**: Flash reseteatu eta fisiko kalibrazio berria egin (`voltage_sensor_align = 10V`). Emaitza zuzena: `ZEA=1.1098, dir=-1`.

### 6. STALL Detekzio Gatazka
`FaultManager` STALL moduan modu-aldaketan berrehuntzen zen (target balioa modu berrian oker interpretatuz).
**Konponketa**: Modu-aldaketan `_stallSince` berrezarri eta `highEffort` baldintza gehitu (STALL soilik potentzia handian aktibatzeko).

---

# Fase 7.1: Alineación Motor-Encoder [ES]

Este ejemplo realiza la alineación eléctrica inicial entre el motor GM3506 y el encoder magnético MT6701 usando SimpleFOC, y valida el control en lazo cerrado en tres modos: Torque, Velocidad y Posición.

## Objetivos
- Ejecutar `motor.initFOC()` para determinar físicamente `zero_electric_angle` y `sensor_direction`.
- Validar el control de **Torque**, **Velocidad** y **Posición** en lazo cerrado sin carga.
- Persistir la calibración en Flash para no recalibrar en cada inicio.

## Características Hardware
- **Motor**: GM3506 gimbal (11 pares de polo, 24N22P)
- **Encoder**: MT6701 (bit-bang SPI, pines PA5/PA6/PA4)
- **Driver**: DRV8316 (6-PWM, SPI dedicado PB3/PB4/PB5)
- **MCU**: STM32G474CEU6

## Instrucciones: Primera Ejecución

### 1. Compilar y cargar
```bash
pio run -e test_foc_advanced --target upload
```

### 2. Desactivar STALL para tuning (solo primera vez)
```
X
```
Salida: `[DIAG] STALL detector: DISABLED (tuning mode)`

### 3. Calibración física (si Flash está vacío o reseteado)
Si aparece `[FLASH] Flash data has UNKNOWN direction`, el motor se alineará automáticamente. La salida correcta es:
```
[MAIN] FOC Initialized successfully.
[CAL] zero_electric_angle = 1.1098
[CAL] sensor_direction    = -1
```
> ⚠️ El motor se bloqueará brevemente durante la alineación. **Asegúrese de que puede girar libremente.**

### 4. Probar modo Torque (verificación de FOC)
```
M C 0      ← Modo torque (Uq directo)
M 2        ← 2V en eje Q
T1         ← Telemetría
```
**Resultado correcto**: `V: ~35 rad/s` y `A:` creciendo continuamente (motor girando).

### 5. Probar modo Velocidad
```
M C 1      ← Modo velocidad cerrada
M V P 2    ← P=2 (P=0.3 insuficiente para superar fricción estática)
M V I 0    ← I=0 para tuning estable sin windup
M 1        ← 1 rad/s objetivo
T1
```
**Resultado correcto**: `V: ~1.00` estable.

### 6. Probar modo Posición
```
M C 2            ← Modo posición (angle mode)
M 800            ← Ir a un ángulo cercano al shaft_angle actual
M 820
```
> **Nota**: `shaft_angle` es acumulativo (multi-vuelta). Usar objetivos cercanos al valor actual de `A:`.

### 7. Guardar calibración
```
S
```
Tras `[FLASH] Calibration saved!`, pulsar **RESET físico** para recargar limpiamente.

### 8. Verificar carga desde Flash
En el siguiente arranque, sin recalibrar:
```
[FLASH] Valid calibration found. Applying...
[CAL] zero_electric_angle = 1.1098
[CAL] sensor_direction    = -1
```

## Referencia de Comandos

| Comando | Descripción |
|---|---|
| `M C 0` | Modo Torque |
| `M C 1` | Modo Velocidad lazo cerrado |
| `M C 2` | Modo Posición |
| `M <valor>` | Fijar objetivo (torque: V, velocidad: rad/s, posición: rad) |
| `M V P <valor>` | Ajustar P del PID de velocidad |
| `M V I <valor>` | Ajustar I del PID de velocidad |
| `O <valor>` | Velocidad en lazo abierto (diagnóstico) |
| `T1` / `T0` | Telemetría ON/OFF |
| `X` | Activar/desactivar detector STALL |
| `S` | Guardar calibración en Flash |
| `R` | Resetear Flash (recalibrará al reiniciar) |
| `C` | Forzar calibración física |
| `D` | Volcar registros DRV8316 |
| `F` | Limpiar fallo STALL y rehabilitar motor |
| `A <valor>` | Aplicar `zero_electric_angle` manualmente |
| `Z` | Diagnóstico de ZEA (en lazo abierto) |

## Resultados de Validación

| Modo | Resultado | Parámetros |
|---|---|---|
| Torque directo | ✅ `V: ~35 rad/s` con `Uq=2V` | `M C 0`, `M 2` |
| Velocidad cerrada | ✅ `V: ~1.00 rad/s` estable | `P=2, I=0` |
| Posición cerrada | ✅ Motor converge al target | `P_angle=5` |
| Carga desde Flash | ✅ Sin recalibración física | `ZEA=1.1098, dir=-1` |

## Troubleshooting / Solución de Problemas
- **El motor vibra pero no gira en modo Torque/Velocidad**: 
  - *Causa*: Posible `zero_electric_angle` incorrecto debido a una calibración donde el rotor no estaba libre.
  - *Solución*: Envíe el comando `R` para resetear la Flash y pulse RESET físico para forzar una nueva calibración libre de fricción.
- **El motor emite un pitido agudo y no se mueve en modo Velocidad**:
  - *Causa*: Ganancia P demasiado baja para superar la fricción estática del motor.
  - *Solución*: Aumente `P` gradualmente (`M V P 2`, `M V P 3`) hasta que logre moverse suavemente.
- **Vibración violenta al usar PID de velocidad**:
  - *Causa*: El término Integral (I) está acumulando error (windup).
  - *Solución*: Ponga la integral a cero (`M V I 0`) hasta encontrar un P estable.
- **El motor salta a un ángulo enorme al activar el modo Posición**:
  - *Causa*: El `shaft_angle` acumula las vueltas de pruebas anteriores (ej. modo torque o abierto).
  - *Solución*: Lea el ángulo actual con telemetría (`T1`) y envíe un objetivo cercano a ese valor, o reinicie la placa.
- **Aparece el error STALL y se deshabilita el motor inmediatamente**:
  - *Causa*: El detector STALL actúa si el motor no se mueve y además está comandando un esfuerzo alto. Durante las pruebas de tuning con ganancias bajas puede suceder.
  - *Solución*: Desactive el STALL temporalmente enviando la letra `X`.

## Bugs Críticos Resueltos

### 1. Conflicto TIM1_BKIN (PA6)
Al inicializar `driver.init()`, el periférico TIM1 reconfiguraba PA6 como función alternativa `BKIN`, rompiendo el encoder MT6701.
**Fix**: Re-afirmar `pinMode()` en PA6 como GPIO tras `driver.init()`.

### 2. Conflicto SPI Global
El objeto `SPI` global podía usar PA5/PA6, colisionando con el bit-banging del encoder.
**Fix**: Instancia `SPIClass` dedicada para el DRV8316 en PB3/PB4/PB5.

### 3. Validación de Calibración en Flash
`resetToDefaults()` establecía `sensor_direction=CW`, generando una calibración falsa.
**Fix**: Default cambiado a `sensor_direction=UNKNOWN (0)`, forzando recalibración real.

### 4. Bloqueo por Escritura en Flash
`HAL_FLASH_Program()` bloquea el loop ~30ms, desincronizando el FOC.
**Fix**: Deshabilitar el motor antes de la escritura y rehabilitarlo tras ella.

### 5. Zero Eléctrico Incorrecto
En una sesión de calibración se obtuvo `ZEA=4.9195, dir=1`, pero no producía torque en lazo cerrado. El motor se bloqueaba sin girar (Uq iba al eje D, no al Q).
**Fix**: Reset de Flash y nueva calibración física. Resultado correcto: `ZEA=1.1098, dir=-1`.

### 6. STALL Falso en Cambios de Modo
El `FaultManager` disparaba STALL al cambiar de modo (el `target` del modo anterior se interpretaba incorrectamente en el nuevo modo).
**Fix**: Resetear `_stallSince` al detectar cambio de modo. Añadir condición `highEffort` (STALL solo si se aplica >50% del voltaje límite).

---

# Phase 7.1: Motor-Encoder Alignment [EN]

This example performs the electrical alignment between the GM3506 motor and the MT6701 magnetic encoder using SimpleFOC, and validates closed-loop control in Torque, Velocity, and Position modes.

## Objectives
- Run `motor.initFOC()` to physically determine `zero_electric_angle` and `sensor_direction`.
- Validate **Torque**, **Velocity**, and **Position** closed-loop control under no load.
- Persist calibration to Flash to avoid re-calibrating on each startup.

## Hardware
- **Motor**: GM3506 gimbal (11 pole pairs, 24N22P)
- **Encoder**: MT6701 (bit-bang SPI, pins PA5/PA6/PA4)
- **Driver**: DRV8316 (6-PWM, dedicated SPI PB3/PB4/PB5)
- **MCU**: STM32G474CEU6

## Instructions: First Use

### 1. Build and Upload
```bash
pio run -e test_foc_advanced --target upload
```

### 2. Disable STALL for tuning
```
X
```
Output: `[DIAG] STALL detector: DISABLED (tuning mode)`

### 3. Physical Calibration (empty or reset Flash)
If `[FLASH] Flash data has UNKNOWN direction` appears, the motor will self-align. Expected output:
```
[MAIN] FOC Initialized successfully.
[CAL] zero_electric_angle = 1.1098
[CAL] sensor_direction    = -1
```
> ⚠️ The motor will briefly lock during alignment. **Ensure it can rotate freely.**

### 4. Validate Torque Mode (FOC verification)
```
M C 0      ← Torque mode (direct Uq)
M 2        ← 2V on Q-axis
T1         ← Enable telemetry
```
**Expected**: `V: ~35 rad/s`, `A:` incrementing continuously.

### 5. Validate Velocity Mode
```
M C 1      ← Closed-loop velocity
M V P 2    ← P=2 (P=0.3 insufficient to overcome static friction)
M V I 0    ← I=0 for stable initial tuning
M 1        ← Target: 1 rad/s
T1
```
**Expected**: `V: ~1.00` stable.

### 6. Validate Position Mode
```
M C 2            ← Position mode
M 800            ← Target near current shaft_angle
M 820
```
> **Note**: `shaft_angle` is cumulative. Use targets near the current `A:` value shown in telemetry.

### 7. Save Calibration
```
S
```
After `[FLASH] Calibration saved!`, press the **physical RESET button** for a clean reload.

### 8. Verify Flash Load
On the next startup, no physical alignment occurs:
```
[FLASH] Valid calibration found. Applying...
[CAL] zero_electric_angle = 1.1098
[CAL] sensor_direction    = -1
```

## Command Reference

| Command | Description |
|---|---|
| `M C 0` | Torque mode |
| `M C 1` | Closed-loop velocity mode |
| `M C 2` | Position mode |
| `M <value>` | Set target (torque: V, velocity: rad/s, position: rad) |
| `M V P <value>` | Set velocity PID P gain |
| `M V I <value>` | Set velocity PID I gain |
| `O <value>` | Open-loop velocity (diagnostic) |
| `T1` / `T0` | Telemetry ON/OFF |
| `X` | Toggle STALL detector |
| `S` | Save calibration to Flash |
| `R` | Reset Flash (will recalibrate on next boot) |
| `C` | Force physical calibration |
| `D` | Dump DRV8316 registers |
| `F` | Clear STALL fault and re-enable motor |
| `A <value>` | Manually set `zero_electric_angle` |
| `Z` | Diagnose ZEA offset (run during open-loop) |

## Validation Results

| Mode | Result | Parameters Used |
|---|---|---|
| Direct torque | ✅ `V: ~35 rad/s` with `Uq=2V` | `M C 0`, `M 2` |
| Closed-loop velocity | ✅ `V: ~1.00 rad/s` stable | `P=2, I=0` |
| Closed-loop position | ✅ Motor converges to target | `P_angle=5` |
| Flash reload | ✅ No physical alignment needed | `ZEA=1.1098, dir=-1` |

## Troubleshooting
- **The motor vibrates but does not spin in Torque/Velocity mode**: 
  - *Cause*: Incorrect `zero_electric_angle`, likely because the rotor was not free during calibration.
  - *Fix*: Send the `R` command to reset the Flash, press the physical RESET button, and allow the motor to self-align without obstruction.
- **The motor emits a high-pitched beep and does not move in Velocity mode**:
  - *Cause*: PID `P` gain is too low to overcome the motor's static friction.
  - *Fix*: Gradually increase `P` (`M V P 2`, `M V P 3`) until it moves smoothly.
- **Violent vibration while tuning Velocity PID**:
  - *Cause*: The Integral (I) term is experiencing windup.
  - *Fix*: Set the integral to zero (`M V I 0`) until a stable P gain is found.
- **The motor spins rapidly to a huge angle when switching to Position mode**:
  - *Cause*: The `shaft_angle` is cumulative and retains all rotations from previous tests (like torque mode).
  - *Fix*: Read the current angle using telemetry (`T1`) and send a target close to that value, or restart the board.
- **STALL fault occurs and motor disables immediately**:
  - *Cause*: The STALL detector triggers if the motor doesn't move despite high effort. During tuning, low gains can trigger this.
  - *Fix*: Temporarily disable the STALL detector by sending the `X` command.

## Critical Bugs Fixed During Development

| Bug | Root Cause | Fix |
|---|---|---|
| Encoder always reads 0 | `driver.init()` reconfigured PA6 as TIM1_BKIN | Re-assert GPIO after `driver.init()` |
| SPI interference | Global `SPI` object touched PA5/PA6 | Dedicated `SPIClass _spi_drv` on PB3/PB4/PB5 |
| Flash loads stale calibration | Default `sensor_direction=CW` bypassed alignment | Default changed to `UNKNOWN (0)` |
| Motor desyncs after Flash save | `HAL_FLASH_Program()` blocks loop ~30ms | Disable motor before save, enable after |
| Wrong `zero_electric_angle` | Motor partially blocked during alignment | `voltage_sensor_align=10V`, fresh calibration |
| False STALL on mode change | Stale `target` misinterpreted in new mode | Reset `_stallSince` on mode change; add `highEffort` condition |

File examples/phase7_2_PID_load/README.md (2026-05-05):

# 7.2 Fasea: PID Doikuntza Kargarekin

Adibide hau PIDs-en doikuntza finerako da, behin pintzak montatuta daudenean eta motorrak benetako karga mekanikoa duenean.

## Helburuak
- `KP`, `KI`, `KD` doitzea pintzen pisuarekin oszilazioak saihesteko.
- **Torque** kontrola balioztatzea `InlineCurrentSense` korronte sentsorearen bidez.
- Korronte muga errealistak definitzea objetuak hartzean ez kaltetzeko.

## Uneko egoera
- **Zai**: Lehenik 7.1 Fasea egin eta hardware mekanikoa montatu.

---

# Fase 7.2: PID Tuning con Carga [ES]

Este ejemplo está destinado al ajuste fino de los PIDs una vez las pinzas están montadas y el motor tiene carga mecánica real.

## Objetivos
- Ajustar `KP`, `KI`, `KD` para evitar oscilaciones con el peso de las pinzas.
- Validar el control de **Par (Torque)** mediante el sensor de corriente `InlineCurrentSense`.
- Definir límites de corriente realistas para evitar dañar objetos durante el agarre.

## Estado actual
- **En espera**: Realizar primero la Fase 7.1 y montar el hardware mecánico.

---

# Phase 7.2: PID Tuning with Load [EN]

This example is intended for fine-tuning the PIDs once the grippers are mounted and the motor has real mechanical load.

## Objectives
- Adjust `KP`, `KI`, `KD` to avoid oscillations with the weight of the grippers.
- Validate **Torque** control using the `InlineCurrentSense` current sensor.
- Define realistic current limits to avoid damaging objects during gripping.

## Current status
- **On hold**: Perform Phase 7.1 first and assemble the mechanical hardware.

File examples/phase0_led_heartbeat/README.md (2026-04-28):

# 0. Fasea: LED Heartbeat (Pre-testa)

Adibide honek STM32-a abiarazten dela eta kodea exekutatzen duela egiaztatzen du. Ez du 24V-eko elikadurarik edo kable gehigarririk behar.

## Beharrezkoak
- ST-Link SWD + Elikadura (ST-Link 3.3V edo USB-C).

## Diagnostikoa
- LEDak 5Hz-ra dir-dir egiten badu (200ms) → STM32 ondo funtzionatzen ari da ✅
- LEDak ez badu dir-dir egiten → Elikadura edo flash arazoa ❌

## Nola Probatu
1. Konpilatu eta kargatu firmwarea ingurune espezifikoa erabiliz:
   ```bash
   pio run -e test_led_heartbeat --target upload
   ```
2. Behatu plakako LEDa (PC6).
3. Serie-monitorean "STM32 Heartbeat OK" mezua ikusi beharko zenuke.

---

# Fase 0: LED Heartbeat (Pre-test) [ES]

Este ejemplo verifica que el STM32 arranca y ejecuta código correctamente. No requiere alimentación de 24V ni cables adicionales.

## Requisitos
- ST-Link SWD + Alimentación (ST-Link 3.3V o USB-C).

## Diagnóstico
- Si el LED parpadea a 5Hz (200ms) → El STM32 está funcionando correctamente ✅
- Si el LED no parpadea → Problema de alimentación o de flasheo ❌

## Cómo Probarlo
1. Compila y carga el firmware usando el entorno específico:
   ```bash
   pio run -e test_led_heartbeat --target upload
   ```
2. Observa el LED de la placa (PC6).
3. En el monitor serie deberías ver el mensaje "STM32 Heartbeat OK".

---

# Phase 0: LED Heartbeat (Pre-test) [EN]

This example verifies that the STM32 starts and executes code correctly. It does not require 24V power or additional cables.

## Requirements
- ST-Link SWD + Power (ST-Link 3.3V or USB-C).

## Diagnosis
- If the LED flashes at 5Hz (200ms) → STM32 is working correctly ✅
- If the LED does not flash → Power or flashing problem ❌

## How to Test
1. Compile and upload the firmware using the specific environment:
   ```bash
   pio run -e test_led_heartbeat --target upload
   ```
2. Observe the board's LED (PC6).
3. In the serial monitor, you should see the message "STM32 Heartbeat OK".

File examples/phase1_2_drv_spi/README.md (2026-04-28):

# 1.2 Fasea — DRV8316 SPI Konfigurazio Testa

Proba-ingurune honek DRV8316 motor-gidariarekin SPI komunikazioa hasieratzen du eta bere egoera-erregistroen (STATUS1 eta STATUS2) aldizkako kontsulta (polling) egiten du.

## Beharrezko Hardwarea
- SCLF Gripper plaka konektatuta.
- **24V-eko elikadura konektatuta** (DRV8316-ak VM tentsio nagusia behar du barne-logika gaitzeko eta SPI bidez erantzuteko).
- USB konexioa VCP atakara serie-monitorearentzat.

## Erabiltzeko Argibideak

1. **Konpilatu eta kargatu:**
   Exekutatu komando hau proiektuaren erroan ingurune espezifiko hau igotzeko:
   ```bash
   pio run -e test_drv_spi --target upload
   ```

2. **Serie-Monitorea:**
   Ireki serie-monitorea 115200-ko baud rate-arekin:
   ```bash
   pio device monitor --baud 115200
   ```

3. **Egiaztapena:**
   - SPI komunikazioa arrakastatsua da monitoreak MISO flotatzaile erroreik ematen ez badu (`(STATUS=0x7FF)`).
   - Testak STATUS1 eta STATUS2-ren balio gordinak erakutsiko ditu etengabe.
   - **Diseinu oharra:** Aldatu gabeko hardwarean (L1 konektatuta), normala da `STATUS2: 0x60` irakurtzea (Buck erreguladorearen UV/OCP akatsa), 3.3V-eko LDO-arekin dagoen gatazka elektrikoagatik. Irakurketa hau lortzeak SPI busa eta liburutegia %100ean funtzionatzen dutela baieztatzen du.

---

# FASE 1.2 — DRV8316 SPI Config Test [ES]

Este entorno de prueba (test) inicializa la comunicación SPI con el driver de motor DRV8316 y ejecuta un sondeo regular (polling) de sus registros de estado (STATUS1 y STATUS2).

## Hardware Requerido
- Placa SCLF Gripper conectada.
- **Alimentación de 24V conectada** (El DRV8316 necesita la tensión de bus principal VM para habilitar la lógica interna y responder por SPI).
- Conexión USB al puerto VCP para el monitor serie.

## Instrucciones de Uso

1. **Compilar y flashear:**
   Ejecuta el siguiente comando en la raíz del proyecto para subir este entorno específico:
   ```bash
   pio run -e test_drv_spi --target upload
   ```

2. **Monitor Serie:**
   Abre el monitor serie con un baud rate de 115200:
   ```bash
   pio device monitor --baud 115200
   ```

3. **Verificación:**
   - La comunicación SPI es exitosa si el monitor no reporta error de MISO flotante (`(STATUS=0x7FF)`).
   - El test mostrará continuamente el valor raw de STATUS1 y STATUS2.
   - **Nota de diseño:** En hardware sin modificar (con L1 conectada), es perfectamente normal leer `STATUS2: 0x60` (Fallo de UV/OCP en el regulador Buck) debido al conflicto eléctrico con el LDO de 3.3V. Obtener esta lectura confirma que el bus SPI y la librería están funcionando al 100%.

---

# Phase 1.2 — DRV8316 SPI Config Test [EN]

This test environment initializes SPI communication with the DRV8316 motor driver and performs regular polling of its status registers (STATUS1 and STATUS2).

## Required Hardware
- SCLF Gripper board connected.
- **24V power supply connected** (The DRV8316 needs the main bus voltage VM to enable internal logic and respond via SPI).
- USB connection to the VCP port for the serial monitor.

## Usage Instructions

1. **Compile and flash:**
   Run the following command in the project root to upload this specific environment:
   ```bash
   pio run -e test_drv_spi --target upload
   ```

2. **Serial Monitor:**
   Open the serial monitor with a baud rate of 115200:
   ```bash
   pio device monitor --baud 115200
   ```

3. **Verification:**
   - SPI communication is successful if the monitor does not report a floating MISO error (`(STATUS=0x7FF)`).
   - The test will continuously display the raw value of STATUS1 and STATUS2.
   - **Design note:** In unmodified hardware (with L1 connected), it is perfectly normal to read `STATUS2: 0x60` (Buck regulator UV/OCP fault) due to the electrical conflict with the 3.3V LDO. Obtaining this reading confirms that the SPI bus and the library are working 100%.

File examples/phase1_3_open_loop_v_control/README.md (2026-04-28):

# 1.3 Fasea - Open Loop Velocity Control (GM3506)

Karpeta honetan 1.3 Fasearen (`1_3_open_loop_v_control`) kode egiaztatua dago. Fase honen helburua iPower GM3506 motorra begizta irekian (open-loop) biraraztea da, DRV8316 6-PWM bidez ondo kontrolatzen dela ziurtatzeko.

### Zergatik egin den?
Fase hau segurtasunagatik egiten dugu. Motorra birarazi aurretik sentsorea motorrarekin lerrokatzen saiatzen bagara (closed-loop), errore batek motorra edo driver-a erre dezake. Hori saihesteko, aurretik motorra modu seguruan biratzen ote den frogatzen dugu, **2.0V-eko muga zorrotza jarrita**.

### Nola probatu

1. Ziurtatu plakaren 24V elikadura **DESKONEKTATUTA** dagoela kableatzen ari zaren bitartean.
2. Motorraren 3 faseak ondo konektatu.
3. Elikatu plaka 24V iturriarekin.
4. Konpilatu eta kargatu firmwarea ingurune espezifikoa erabiliz:
   ```bash
   pio run -e test_open_loop --target upload
   ```
5. Ireki Serie Monitorea (USB kablea Gripper-era konektatuta):
   ```bash
   pio device monitor --baud 115200
   ```
6. Idatzi terminalean eta bidali `T1` agindua motorra 1 rad/s abiaduran biratzeko. `T2` jarri dezakezu azkarrago biratzeko.
7. Geratzeko, bidali `T0`.

### Motorraren ezaugarriak (iPower GM3506 130T)
- **Poloak (Poles):** 14
- **Polo-pareak (Pole pairs):** 7
- **Bira (Turns):** 130
- **Erresistentzia:** 12.5 Ω
- **Tentsio gomendatua:** 11.1V

---

# Fase 1.3 - Control de Velocidad en Lazo Abierto (GM3506) [ES]

En esta carpeta se encuentra el código verificado de la Fase 1.3 (`1_3_open_loop_v_control`). El objetivo de esta fase es hacer girar el motor iPower GM3506 en lazo abierto (open-loop) para asegurar que el DRV8316 lo controla correctamente mediante 6-PWM.

### ¿Por qué se hace?
Esta fase se realiza por seguridad. Si intentamos alinear el sensor con el motor (lazo cerrado) antes de comprobar que el motor gira, un error podría quemar el motor o el driver. Para evitarlo, probamos primero si el motor gira de forma segura, estableciendo un **límite estricto de 2.0V**.

### Cómo Probarlo

1. Asegúrate de que la alimentación de 24V de la placa esté **DESCONECTADA** mientras realizas el cableado.
2. Conecta correctamente las 3 fases del motor.
3. Alimenta la placa con una fuente de 24V.
4. Compila y carga el código usando el entorno específico:
   ```bash
   pio run -e test_open_loop --target upload
   ```
5. Abre el Monitor Serie (con el cable USB conectado al Gripper):
   ```bash
   pio device monitor --baud 115200
   ```
6. Escribe en la terminal y envía el comando `T1` para que el motor gire a 1 rad/s. Puedes poner `T2` para que gire más rápido.
7. Para parar, envía `T0`.

### Características del Motor (iPower GM3506 130T)
- **Polos:** 14
- **Pares de polos:** 7
- **Vueltas (Turns):** 130
- **Resistencia:** 12.5 Ω
- **Tensión recomendada:** 11.1V

---

# Phase 1.3 - Open Loop Velocity Control (GM3506) [EN]

This folder contains the verified code for Phase 1.3 (`1_3_open_loop_v_control`). The goal of this phase is to rotate the iPower GM3506 motor in open-loop to ensure it is correctly controlled by the DRV8316 via 6-PWM.

### Why is it done?
This phase is performed for safety. If we attempt to align the sensor with the motor (closed-loop) before verifying that the motor rotates, an error could burn the motor or the driver. To prevent this, we first test if the motor rotates safely, setting a **strict 2.0V limit**.

### How to Test

1. Ensure the board's 24V power supply is **DISCONNECTED** while wiring.
2. Correctly connect the 3 motor phases.
3. Power the board with a 24V source.
4. Compile and upload the code using the specific environment:
   ```bash
   pio run -e test_open_loop --target upload
   ```
5. Open the Serial Monitor (with the USB cable connected to the Gripper):
   ```bash
   pio device monitor --baud 115200
   ```
6. Type in the terminal and send the `T1` command to make the motor rotate at 1 rad/s. You can use `T2` to make it rotate faster.
7. To stop, send `T0`.

### Motor Characteristics (iPower GM3506 130T)
- **Poles:** 14
- **Pole pairs:** 7
- **Turns:** 130
- **Resistance:** 12.5 Ω
- **Recommended voltage:** 11.1V

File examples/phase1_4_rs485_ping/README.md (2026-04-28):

# 1.4 Fasea: RS485 Ping-Pong Testa

Adibide honek MAX3485 transzeptorea erabiliz oinarrizko RS485 komunikazioa erakusten du. Ping-Pong logika sinple bat inplementatzen du, non gailuak "PING" komandoari "PONG" mezuarekin erantzuten dion.

## Ezaugarri Nagusiak
- **Protokolo Sinplifikatua**: Hitz bakarreko komandoak onartzen ditu (bi punturik gabe). Bidali `PING` mezua `1:PING:0` bidali ordez.
- **VCP Simulazioa**: Logika zuzenean USB Virtual COM Port (Serie Monitorea) bidez probatzeko aukera ematen du, RS485-USB moldagailurik behar izan gabe.
- **Ikusizko Feedback-a**: LEDa (PC6) 1Hz-ra dir-dir egiten du martxan dagoen bitartean.

## Nola Probatu

### A Aukera: USB soilik erabiliz (Virtual COM Port)
1. Konpilatu eta kargatu firmwarea ingurune espezifikoa erabiliz:
   ```bash
   pio run -e test_rs485_ping --target upload
   ```
2. Ireki serie-monitorea 115200 baudean.
3. Idatzi `PING` eta sakatu Enter.
4. Hau ikusi beharko zenuke:
   ```text
   [RS485 Rx] CMD: PING
     -> Received PING! Sending PONG...
   [VCP] Reply sent to RS485 bus: 1:PONG:0
   ```

### B Aukera: RS485-USB moldagailua erabiliz (Bus fisikoa)
1. Konektatu moldagailuaren A/B lineak Gripper-era.
2. Bidali `1:PING:0\n` edo `PING\n` katea PCtik RS485 moldagailuaren bidez.
3. Gripper-ak `1:PONG:0\n` erantzun beharko luke.

---

# Fase 1.4: Test de Ping-Pong RS485 [ES]

Este ejemplo muestra la comunicación básica RS485 utilizando el transceptor MAX3485. Implementa una lógica simple de Ping-Pong donde el dispositivo responde a un comando "PING" con "PONG".

## Características Principales
- **Protocolo Simplificado**: Soporta comandos de una sola palabra (sin necesidad de dos puntos). Envía `PING` en lugar de `1:PING:0`.
- **Simulación VCP**: Permite probar la lógica directamente a través del puerto USB Virtual COM (Monitor Serie) sin necesidad de un adaptador RS485-USB.
- **Feedback Visual**: El LED (PC6) parpadea a 1Hz durante el funcionamiento.

## Cómo Probarlo

### Opción A: Usando solo USB (Virtual COM Port)
1. Compila y carga el firmware usando el entorno específico:
   ```bash
   pio run -e test_rs485_ping --target upload
   ```
2. Abre el monitor serie a 115200 baudios.
3. Escribe `PING` y pulsa Enter.
4. Deberías ver:
   ```text
   [RS485 Rx] CMD: PING
     -> Received PING! Sending PONG...
   [VCP] Reply sent to RS485 bus: 1:PONG:0
   ```

### Opción B: Usando adaptador RS485-USB (Bus físico)
1. Conecta las líneas A/B del adaptador al Gripper.
2. Envía la cadena `1:PING:0\n` o simplemente `PING\n` desde el PC a través del adaptador RS485.
3. El Gripper debería responder con `1:PONG:0\n`.

---

# Phase 1.4: RS485 Ping-Pong Test [EN]

This example demonstrates basic RS485 communication using the MAX3485 transceiver. It implements a simple Ping-Pong logic where the device responds to a "PING" command with "PONG".

## Key Features
- **Simplified Protocol**: Supports single-word commands (no colons required). Send `PING` instead of `1:PING:0`.
- **VCP Simulation**: Allows testing the logic directly via the USB Virtual COM Port (Serial Monitor) without needing an RS485-USB adapter.
- **Visual Feedback**: LED (PC6) heartbeats at 1Hz during operation.

## How to Test

### Option A: Using only USB (Virtual COM Port)
1. Compile and upload the firmware using the specific environment:
   ```bash
   pio run -e test_rs485_ping --target upload
   ```
2. Open the serial monitor at 115200 baud.
3. Type `PING` and press Enter.
4. You should see:
   ```text
   [RS485 Rx] CMD: PING
     -> Received PING! Sending PONG...
   [VCP] Reply sent to RS485 bus: 1:PONG:0
   ```

### Option B: Using RS485-USB adapter (Physical Bus)
1. Connect the A/B lines of the adapter to the Gripper.
2. Send the string `1:PING:0\n` or just `PING\n` from the PC through the RS485 adapter.
3. The Gripper should respond with `1:PONG:0\n`.

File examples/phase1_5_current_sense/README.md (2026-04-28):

# 1.5 Fasea: Korronte-Sentsorearen Balioztatzea

Adibide honek motorraren faseetako korronteak nola irakurtzen diren erakusten du, DRV8316 driver-ak dituen korronte-anplifikadore integratuak erabiliz.

## Ezaugarri Nagusiak
- **CSA Integratua**: DRV8316-ren barneko korronte-anplifikadoreak (Current Sense Amplifiers) erabiltzen ditu.
- **SimpleFOC Integrazioa**: `InlineCurrentSense` erabiltzen du ADC irakurketak Amperetara bihurtzeko.
- **Offset Kalibrazioa**: Abiaraztean automatikoki kalibratzen du zero-korrontearen offset-a.
- **Serie-Monitorea**: CURA, CURB eta CURC korronteak inprimatzen ditu (Amperetan) arazketarako.

## Hardware Konfigurazioa
- **MCU Pinak**: PA0 (CURA), PA1 (CURB), PA2 (CURC).
- **Gidaria (Driver)**: DRV8316 elikatuta egon behar da (VM > 8V) anplifikadoreek funtziona dezaten.
- **Irabazia (Gain)**: SPI bidez konfiguratua (0.3 V/A-ko balio lehenetsia test honetan).

## Nola Probatu
1. Konpilatu eta kargatu firmwarea ingurune espezifikoa erabiliz:
   ```bash
   pio run -e test_current_sense --target upload
   ```
2. Ireki serie-monitorea 115200 baudean.
3. Plakak lehenik offset-ak kalibratuko ditu (ziurtatu motorra ez dela mugitzen eta korronterik ez dabilela).
4. Behatu korronte irakurketak. Motorra kargarik gabe dagoenean, 0.00A-tik hurbil egon beharko lukete.
5. Motorra eskuz biratzen baduzu edo lazo irekian karga aplikatzen baduzu, balioak aldatzen direla ikusiko duzu.

---

# Fase 1.5: Validación del Sensor de Corriente [ES]

Este ejemplo muestra cómo leer las corrientes de fase del motor utilizando los amplificadores de detección de corriente integrados del DRV8316.

## Características Principales
- **CSA Integrado**: Utiliza los amplificadores de detección de corriente (CSA) internos del DRV8316.
- **Integración con SimpleFOC**: Utiliza `InlineCurrentSense` para mapear las lecturas del ADC a Amperios.
- **Calibración de Offset**: Calibra automáticamente el offset de corriente cero al arrancar.
- **Salida por Monitor Serie**: Imprime CURA, CURB y CURC en Amperios para depuración.

## Configuración de Hardware
- **Pines MCU**: PA0 (CURA), PA1 (CURB), PA2 (CURC).
- **Driver**: El DRV8316 debe estar alimentado (VM > 8V) para que los amplificadores funcionen.
- **Ganancia (Gain)**: Configurada vía SPI (por defecto 0.3 V/A en este test).

## Cómo Probarlo
1. Compila y carga el código usando el entorno específico:
   ```bash
   pio run -e test_current_sense --target upload
   ```
2. Abre el monitor serie a 115200 baudios.
3. La placa primero calibrará los offsets (asegúrate de que el motor no se mueva y no fluya corriente).
4. Observa las lecturas de corriente. Sin carga en el motor, deberían estar cerca de 0.00A.
5. Si giras el motor manualmente o aplicas una carga en lazo abierto, verás que los valores cambian.

---

# Phase 1.5: Current Sense Validation [EN]

This example demonstrates how to read motor phase currents using the integrated current-sense amplifiers of the DRV8316.

## Key Features
- **Integrated CSA**: Uses the DRV8316's internal current sense amplifiers.
- **SimpleFOC Integration**: Uses `InlineCurrentSense` to map ADC readings to Amperes.
- **Offset Calibration**: Automatically calibrates the zero-current offset at startup.
- **Serial Monitor Output**: Prints CURA, CURB, and CURC in Amps for debugging.

## Hardware Setup
- **MCU Pins**: PA0 (CURA), PA1 (CURB), PA2 (CURC).
- **Driver**: DRV8316 must be powered (VM > 8V) for the amplifiers to work.
- **Gain**: Configured via SPI (defaulting to 0.3 V/A in this test).

## How to Test
1. Compile and upload the firmware using the specific environment:
   ```bash
   pio run -e test_current_sense --target upload
   ```
2. Open the serial monitor at 115200 baud.
3. The board will first calibrate offsets (ensure motor is not moving and no current is flowing).
4. Observe the current readings. Without motor load, they should be close to 0.00A.
5. If you rotate the motor manually or apply a load in open loop, you should see the values change.

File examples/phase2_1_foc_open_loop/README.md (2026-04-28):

# 2.1 Fasea — FOC Open-Loop Testa

Test honek motorraren biraketa lazo irekian (Open-Loop) balioztatzen du, **SimpleFOC** liburutegia eta `MotorController` wrapper klasea erabiliz.

## Helburua
- Motorraren biraketa suabea egiaztatzea encoder-aren lerrokatzerik behar izan gabe.
- Hardwarean faseen alderantzikapena (C-B-A) softwarearen konfigurazioarekin bat datorrela balioztatzea.
- DRV8316 driver-a eta potentzia-etapa kargapean (8V-eko muga) funtzionatzen dutela egiaztatzea.

## Hardware Baldintzak
- **24V**-eko elikadura iturria.
- ST-Link konexioa firmwarea igotzeko.
- USB-C kablea gripper-aren atakara konektatuta telemetriarako.

## Nola egin testa

1. **Konpilatu eta kargatu**:
   Exekutatu komando hau proiektuaren erroan ingurune espezifiko hau igotzeko:
   ```bash
   pio run -e test_foc_open_loop --target upload
   ```

2. **Serie-Monitorea**:
   - Ireki serie-monitorea **115200 baudean**.
   - `[MC] System Initialized OK` mezua ikusi beharko zenuke.
   - Sistema lehenetsita `MotionControlType::velocity_openloop` moduan abiatzen da.

3. **Proba Komandoak**:
   - `M10`: Motorra 10 rad/s-ra birarazten du erlojuaren noranzkoan.
   - `M-10`: Motorra -10 rad/s-ra birarazten du (kontrako noranzkoan).
   - `M0`: Motorra gelditzen du.
   - `ME0`: Motorra ezgaitzen du (torque zero).
   - `ME1`: Motorra gaitzen du.

4. **Egiaztapena**:
   - Behatu motorra modu suabe eta isilean biratzen den.
   - Egiaztatu `Ang` eta `Vel` balioak aldizkako txostenean. Kontrola lazo irekian izan arren, MT6701 encoder-ak benetako biraketa angelua erakutsi beharko luke.

## Diagnostikoa
- Motorrak zarata edo bibrazioa egiten badu baina biratzen ez bada: Egiaztatu elikadura iturriak korronte nahikoa duela (gutxienez 1.5A) eta `PIN_AH/AL...` pinek zirkuitulaburrik ez dutela.
- Monitoreak daturik erakusten ez badu: Berrikusi `HSI48` erlojuaren konfigurazioa `main.cpp`-n (`MotorController` bidez) USB CDC-rako.

---

# Phase 2.1 — FOC Open-Loop Test [ES]

Este test valida la rotación del motor en lazo abierto (Open-Loop) utilizando la librería **SimpleFOC** y la clase wrapper `MotorController`.

## Objetivo
- Verificar la rotación suave del motor sin necesidad de alineación del encoder.
- Validar que la inversión de fases (C-B-A) en el hardware coincide con la configuración del software.
- Comprobar que el driver DRV8316 y la etapa de potencia funcionan bajo carga (8V límite).

## Requisitos de Hardware
- Fuente de alimentación a **24V**.
- Conexión ST-Link para el flasheo.
- Cable USB-C conectado al puerto del gripper para telemetría.

## Cómo realizar el test

1. **Compilar y flashear**:
   Ejecuta el siguiente comando en la raíz del proyecto para subir este entorno específico:
   ```bash
   pio run -e test_foc_open_loop --target upload
   ```

2. **Monitor Serie**:
   - Abre el monitor serie a **115200 baudios**.
   - Deberías ver el mensaje: `[MC] System Initialized OK`.
   - El sistema arranca por defecto en `MotionControlType::velocity_openloop`.

3. **Comandos de Prueba**:
   - `M10`: Hace girar el motor a 10 rad/s en sentido horario.
   - `M-10`: Hace girar el motor a -10 rad/s (sentido antihorario).
   - `M0`: Detiene el motor.
   - `ME0`: Deshabilita el motor (torque cero).
   - `ME1`: Habilita el motor.

4. **Verificación**:
   - Observa si el motor gira de forma suave y silenciosa.
   - Verifica los valores de `Ang` y `Vel` en el reporte periódico. Aunque el control sea en lazo abierto, el encoder bit-bang MT6701 debería estar reportando el ángulo real de giro.

## Diagnóstico
- Si el motor hace ruido o vibra pero no gira: Verifica que la fuente de alimentación tenga corriente suficiente (mínimo 1.5A) y que los pines `PIN_AH/AL...` no tengan cortocircuitos.
- Si el monitor no muestra datos: Revisa la configuración del reloj `HSI48` en `main.cpp` (vía `MotorController`) para el USB CDC.

---

# Phase 2.1 — FOC Open-Loop Test [EN]

This test validates the motor rotation in open-loop using the **SimpleFOC** library and the `MotorController` wrapper class.

## Objective
- Verify smooth motor rotation without the need for encoder alignment.
- Validate that the phase reversal (C-B-A) in hardware matches the software configuration.
- Check that the DRV8316 driver and power stage function under load (8V limit).

## Hardware Requirements
- **24V** power supply.
- ST-Link connection for flashing.
- USB-C cable connected to the gripper port for telemetry.

## How to Perform the Test

1. **Compile and upload**:
   Run the following command in the project root to upload this specific environment:
   ```bash
   pio run -e test_foc_open_loop --target upload
   ```

2. **Serial Monitor**:
   - Open the serial monitor at **115200 baud**.
   - You should see the message: `[MC] System Initialized OK`.
   - The system starts by default in `MotionControlType::velocity_openloop`.

3. **Test Commands**:
   - `M10`: Rotates the motor at 10 rad/s clockwise.
   - `M-10`: Rotates the motor at -10 rad/s (counter-clockwise).
   - `M0`: Stops the motor.
   - `ME0`: Disables the motor (zero torque).
   - `ME1`: Enables the motor.

4. **Verification**:
   - Observe if the motor rotates smoothly and quietly.
   - Verify the `Ang` and `Vel` values in the periodic report. Even though the control is in open-loop, the MT6701 bit-bang encoder should be reporting the actual rotation angle.

## Diagnosis
- If the motor makes noise or vibrates but does not rotate: Verify that the power supply has enough current (minimum 1.5A) and that the `PIN_AH/AL...` pins do not have short circuits.
- If the monitor does not show data: Review the `HSI48` clock configuration in `main.cpp` (via `MotorController`) for USB CDC.

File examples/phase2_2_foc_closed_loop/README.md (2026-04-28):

# 2.2 Fasea — FOC Closed-Loop Testa

Test honek motorraren biraketa lazo itxian (Closed-Loop Velocity) balioztatzen du, **MT6701** encoder-a (bit-banging bidez) eta **DRV8316** driver-a erabiliz.

## Helburua
- Encoder-aren eta motorraren faseen arteko lerrokatze automatikoa (`initFOC`) egitea.
- Abiadura kontrola lazo itxian balioztatzea.
- Hasierako PID irabazien egonkortasuna egiaztatzea (`P=0.5`, `I=5.0`).

## Nola egin testa

1. **Konpilatu eta kargatu**:
   Exekutatu komando hau proiektuaren erroan ingurune espezifiko hau igotzeko:
   ```bash
   pio run -e test_foc_closed_loop --target upload
   ```

2. **Lerrokatzea (GARRANTZITSUA)**:
   - Abiaraztean, motorrak mugimendu txiki bat egingo du encoder-a lerrokatzeko. **Ziurtatu motorra libreki biratu daitekeela** (karga blokeatzailerik gabe).
   - Serie-monitorean lerrokatzearen emaitzak ikusiko dituzu: `Zero electric angle` eta `Sensor direction`.

3. **Serie-Monitorea**:
   - `[MC] Starting in CLOSED-LOOP VELOCITY mode` ikusi beharko zenuke.
   - Motorra orain abiadura komando baten zain dago.

4. **Komando erabilgarriak**:
   - `ME1`: Motorra gaitzen du (posizioa/abiadura mantentzen du).
   - `ME0`: Ezgaitzen du (motorra libre geratzen da).
   - `M<balioa>`: Helburu-abiadura ezartzen du rad/s-tan (adibidez, `M5` = 5 rad/s).
   - `D`: DRV8316-ren erregistroak eta uneko FOC parametroak erakusten ditu.
   - `R`: Sentsorearen birkalibrazioa behartzen du.

---

### ⚠️ Abiadura aldaketak: erabili arrapala progresiboak

Abiadura altu batetik baxu batera bat-batean pasatzean (adibidez, `M15` → `M0`), motorrak dardara bortitza egiten du. Hau gertatzen da errotorearen inertziak uneko irabaziekin PIDak duen baliratzeko gaitasuna gainditzen duelako.

**Gomendatutako proba sekuentzia:**

```
ME1    → Gaitzea
M2     → Irteerako abiadura baxua
M5     → Suabe igo
M10    → Abiadura ertaina
M15    → Abiadura altua (nahi izanez gero)
M10    → Progresiboki jaitsi
M5
M2
M0     → Gelditu
ME0    → Ezgaitu
```

> **Etorkizuneko oharra:** Benetako sisteman integratzeko, abiadura-profil trapezoidalak inplementatu beharko dira (azelerazio/dezelerazio kontrolatua), portaera hau saihesteko. Ikusi Backlog-a `TASKS.md` fitxategian.

---

## Egiaztapena

- Motorrak abiadura lazo irekian baino askoz modu zehatzagoan mantentzen du.
- Motorra **nabarmen gutxiago berotzen da** lazo irekian baino, FOC kommutazioari esker.
- Saiatu ardatza eskuz pixka bat frenatzen (kontu handiz!); motorrak torquea nola handitzen duen sentitu beharko zenuke konpentsatzeko.

---

## Testaren emaitzak (2026-04-21)

**Hardwarea:** SCLF Gripper v2.0 | Motorra: GM3506 (11 pp) | Iturria: 24V

**Telemetria 5 rad/s-ra:**
```
Ang:0.086 rad | Vel:5.23 rad/s | Target:5.00
Ang:3.887 rad | Vel:4.43 rad/s | Target:5.00
Ang:1.387 rad | Vel:4.74 rad/s | Target:5.00
Ang:5.161 rad | Vel:5.07 rad/s | Target:5.00
Ang:2.650 rad | Vel:5.03 rad/s | Target:5.00
```
→ Abiadura errorea ≈ ±0.5 rad/s (±10%) lehenetsitako PID irabaziekin. ✅

**Lortutako FOC kalibrazio parametroak:**
```
Motor Status:      4  (motor_ready)
Sensor Direction: -1  (alderantzikatua — CW fisikoa = CCW elektrikoa)
Zero Elec Angle:   1.3426 rad
```

**DRV8316 erregistroak:** Denak `0x000` → ez dago akats aktiborik. ✅

---

## Diagnostikoa

| Sintoma | Arrazoi posiblea | Konponbidea |
|---|---|---|
| Lerrokatzeak huts egiten du | Encoderra deskonektatuta edo CS okerra | Berrikusi PA4/PA5/PA6 eta encoderraren konektorea |
| Motorrak bibratzen du `ME1` aktibatzean | Sentsorearen norabidea okerra edo angelu elektriko ezegonkorra | Berrabiarazi edo bidali `R` birkalibratzeko |
| Motorrak bibratzen du frenatzean | Abiadura aldaketa zakarra (adibidez, `M15`→`M0`) | Erabili beti arrapala progresiboak (ikus aurreko atala) |

---

# Phase 2.2 — FOC Closed-Loop Test [ES]

Este test valida la rotación del motor en lazo cerrado (Closed-Loop Velocity) utilizando el encoder **MT6701** (vía bit-banging) y el driver **DRV8316**.

## Objetivo
- Realizar la alineación automática (`initFOC`) del encoder con las fases del motor.
- Validar el control de velocidad en lazo cerrado.
- Verificar la estabilidad de las ganancias PID iniciales (`P=0.5`, `I=5.0`).

## Cómo realizar el test

1. **Compilar y flashear**:
   Ejecuta el siguiente comando en la raíz del proyecto para subir este entorno específico:
   ```bash
   pio run -e test_foc_closed_loop --target upload
   ```

2. **Alineación (IMPORTANTE)**:
   - Al arrancar, el motor realizará un pequeño movimiento para alinear el encoder. **Asegúrate de que el motor pueda girar libremente** (sin carga bloqueante).
   - En el monitor serie verás los resultados de la alineación: `Zero electric angle` y `Sensor direction`.

3. **Monitor Serie**:
   - Deberías ver: `[MC] Starting in CLOSED-LOOP VELOCITY mode`.
   - El motor está ahora esperando un comando de velocidad.

4. **Comandos disponibles**:
   - `ME1`: Habilita el motor (mantiene la posición/velocidad).
   - `ME0`: Deshabilita (el motor queda suelto).
   - `M<val>`: Establece la velocidad objetivo en rad/s (ej. `M5` = 5 rad/s).
   - `D`: Vuelca los registros del DRV8316 y los parámetros FOC actuales.
   - `R`: Fuerza una recalibración del sensor.

---

### ⚠️ Cambios de velocidad: usar rampas progresivas

Al pasar de una velocidad alta a una baja de forma brusca (p.e. `M15` → `M0`), el motor vibra violentamente. Esto se debe a que la inercia del rotor supera la capacidad de frenado del PID con las ganancias actuales.

**Secuencia de prueba recomendada:**

```
ME1    → Habilitar
M2     → Velocidad baja de partida
M5     → Subir suavemente
M10    → Velocidad media
M15    → Velocidad alta (si se desea)
M10    → Bajar progresivamente
M5
M2
M0     → Parar
ME0    → Deshabilitar
```

> **Nota de futuro:** Para la integración en el sistema real habrá que implementar perfiles de velocidad trapezoidales (aceleración/deceleración controlada) que eviten este comportamiento. Ver Backlog en `TASKS.md`.

---

## Verificación

- El motor mantiene la velocidad de forma mucho más precisa que en lazo abierto.
- El motor se **calienta significativamente menos** que en lazo abierto gracias a la conmutación FOC.
- Intenta frenar ligeramente el eje con la mano (¡con cuidado!); deberías sentir cómo el motor aumenta el torque para compensar.

---

## Resultados del test (2026-04-21)

**Hardware:** SCLF Gripper v2.0 | Motor: GM3506 (11 pp) | Fuente: 24V

**Telemetría a 5 rad/s:**
```
Ang:0.086 rad | Vel:5.23 rad/s | Target:5.00
Ang:3.887 rad | Vel:4.43 rad/s | Target:5.00
Ang:1.387 rad | Vel:4.74 rad/s | Target:5.00
Ang:5.161 rad | Vel:5.07 rad/s | Target:5.00
Ang:2.650 rad | Vel:5.03 rad/s | Target:5.00
```
→ Error de velocidad ≈ ±0.5 rad/s (±10%) con ganancias PID por defecto. ✅

**Parámetros de calibración FOC obtenidos:**
```
Motor Status:      4  (motor_ready)
Sensor Direction: -1  (invertido — CW físico = CCW eléctrico)
Zero Elec Angle:   1.3426 rad
```

**Registros DRV8316:** Todos a `0x000` → sin fallos activos. ✅

---

## Diagnóstico

| Síntoma | Causa probable | Solución |
|---|---|---|
| Alineación fallida | Encoder desconectado o CS incorrecto | Revisar PA4/PA5/PA6 y el conector del encoder |
| Motor vibra al activar `ME1` | Dirección del sensor incorrecta o ángulo eléctrico inestable | Reiniciar o enviar `R` para recalibrar |
| Motor vibra al frenar | Cambio brusco de velocidad (ej. `M15`→`M0`) | Usar siempre rampas progresivas (ver sección anterior) |

---

# Phase 2.2 — FOC Closed-Loop Test [EN]

This test validates the motor rotation in closed-loop (Closed-Loop Velocity) using the **MT6701** encoder (via bit-banging) and the **DRV8316** driver.

## Objective
- Perform automatic alignment (`initFOC`) of the encoder with the motor phases.
- Validate closed-loop velocity control.
- Verify the stability of the initial PID gains (`P=0.5`, `I=5.0`).

## How to Perform the Test

1. **Compile and upload**:
   Run the following command in the project root to upload this specific environment:
   ```bash
   pio run -e test_foc_closed_loop --target upload
   ```

2. **Alignment (IMPORTANT)**:
   - Upon startup, the motor will perform a small movement to align the encoder. **Ensure the motor can rotate freely** (without blocking load).
   - In the serial monitor, you will see the alignment results: `Zero electric angle` and `Sensor direction`.

3. **Serial Monitor**:
   - You should see: `[MC] Starting in CLOSED-LOOP VELOCITY mode`.
   - The motor is now waiting for a velocity command.

4. **Available Commands**:
   - `ME1`: Enables the motor (maintains position/velocity).
   - `ME0`: Disables the motor (the motor becomes loose).
   - `M<val>`: Sets the target velocity in rad/s (e.g., `M5` = 5 rad/s).
   - `D`: Dumps DRV8316 registers and current FOC parameters.
   - `R`: Forces a sensor recalibration.

---

### ⚠️ Velocity changes: use progressive ramps

When switching from high speed to low speed abruptly (e.g., `M15` → `M0`), the motor vibrates violently. This is because the rotor's inertia exceeds the PID's braking capacity with the current gains.

**Recommended test sequence:**

```
ME1    → Enable
M2     → Low starting speed
M5     → Increase smoothly
M10    → Medium speed
M15    → High speed (if desired)
M10    → Decrease progressively
M5
M2
M0     → Stop
ME0    → Disable
```

> **Future Note:** For integration into the real system, trapezoidal velocity profiles (controlled acceleration/deceleration) must be implemented to avoid this behavior. See Backlog in `TASKS.md`.

---

## Verification

- The motor maintains speed much more precisely than in open-loop.
- The motor **heats up significantly less** than in open-loop thanks to FOC switching.
- Try to lightly brake the shaft with your hand (carefully!); you should feel the motor increase torque to compensate.

---

## Test Results (2026-04-21)

**Hardware:** SCLF Gripper v2.0 | Motor: GM3506 (11 pp) | Power: 24V

**Telemetry at 5 rad/s:**
```
Ang:0.086 rad | Vel:5.23 rad/s | Target:5.00
Ang:3.887 rad | Vel:4.43 rad/s | Target:5.00
Ang:1.387 rad | Vel:4.74 rad/s | Target:5.00
Ang:5.161 rad | Vel:5.07 rad/s | Target:5.00
Ang:2.650 rad | Vel:5.03 rad/s | Target:5.00
```
→ Velocity error ≈ ±0.5 rad/s (±10%) with default PID gains. ✅

**FOC calibration parameters obtained:**
```
Motor Status:      4  (motor_ready)
Sensor Direction: -1  (inverted — physical CW = electrical CCW)
Zero Elec Angle:   1.3426 rad
```

**DRV8316 Registers:** All at `0x000` → no active faults. ✅

---

## Diagnosis

| Symptom | Probable cause | Solution |
|---|---|---|
| Alignment failed | Encoder disconnected or incorrect CS | Check PA4/PA5/PA6 and the encoder connector |
| Motor vibrates when activating `ME1` | Incorrect sensor direction or unstable electrical angle | Restart or send `R` to recalibrate |
| Motor vibrates when braking | Abrupt speed change (e.g., `M15`→`M0`) | Always use progressive ramps (see previous section) |

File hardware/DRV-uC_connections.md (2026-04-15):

# Driver (DRV8316CRRGFR) - Microcontroller (STM32G474CEU6) connections

| Driver pin | Signal name | Microcontroller pin | Alternate Function (TIM) |
|---|---|---|---|
| 22 nFAULT | DRV_FAULT | 2 PC13 | TIM8_CH4N |
| 27 INHA | AH | 32 PA10 | TIM1_CH3 |
| 28 INLA | AL | 28 PB15 | TIM1_CH3N |
| 29 INHB | BH | 31 PA9 | TIM1_CH2 |
| 30 INLB | BL | 27 PB14 | TIM1_CH2N |
| 31 INHC | CH | 30 PA8 | TIM1_CH1 |
| 32 INLC | CL | 26 PB13 | TIM1_CH1N |
| 33 SDO | DRV_MISO | 42 PB4 | SPI1_MISO / SPI3_MISO |
| 34 SDI | DRV_MOSI | 43 PB5 | SPI1_MOSI / SPI3_MOSI |
| 35 SCLK | DRV_CLK | 41 PB3 | SPI1_SCK / SPI3_SCK |
| 36 nSCS | DRV_CS | 16 PC4 | GPIO |
| 38 SOC | CURC | 10 PA2 | ADC |
| 39 SOB | CURB | 9 PA1 | ADC |
| 40 SOA | CURA | 8 PA0 | ADC |

## Additional Device Connections
### MT6701 Encoder (SPI)
| Encoder Pin | Signal | Microcontroller pin |
|---|---|---|
| CS | ENC_CS | 12 PA4 |
| CLK | ENC_CLK | 13 PA5 |
| DO | ENC_SDO | 14 PA6 |

### RS485 Interface
| RS485 Pin | Signal | Microcontroller pin |
|---|---|---|
| DI | RS485_TX | 39 PC10 |
| RO | RS485_RX | 40 PC11 |
| DE/RE | RS485_DIR | 47 PB9 |

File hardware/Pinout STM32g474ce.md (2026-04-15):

# Pinout del Microcontrolador

| Pin | Nombre | Tipo | Funciones Alternas | Funciones Adicionales |
| :--- | :--- | :---: | :--- | :--- |
| 1 | VBAT | S | - | - |
| 2 | PC13 | I/O | TIM1_BKIN, TIM1_CH1N, TIM8_CH4N, EVENTOUT | WKUP2, RTC_TAMP1, RTC_TS, RTC_OUT1 |
| 3 | PC14-OSC32_IN | I/O | EVENTOUT | OSC32_IN |
| 4 | PC15-OSC32_OUT | I/O | EVENTOUT | OSC32_OUT |
| 5 | PF0-OSC_IN | I/O | I2C2_SDA, SPI2_NSS/I2S2_WS, TIM1_CH3N, EVENTOUT | ADC1_IN10, OSC_IN |
| 6 | PF1-OSC_OUT | I/O | SPI2_SCK/I2S2_CK, EVENTOUT | ADC2_IN10, COMP3_INM, OSC_OUT |
| 7 | PG10-NRST | I/O | MCO, EVENTOUT | NRST |
| 8 | PA0 | I/O | TIM2_CH1, TIM5_CH1, USART2_CTS, COMP1_OUT, TIM8_BKIN, TIM8_ETR, TIM2_ETR, EVENTOUT | ADC12_IN1, COMP1_INM, COMP3_INP, RTC_TAMP2, WKUP1 |
| 9 | PA1 | I/O | RTC_REFIN, TIM2_CH2, TIM5_CH2, USART2_RTS_DE, TIM15_CH1N, EVENTOUT | ADC12_IN2, COMP1_INP, OPAMP1_VINP, OPAMP3_VINP, OPAMP6_VINM |
| 10 | PA2 | I/O | TIM2_CH3, TIM5_CH3, USART2_TX, COMP2_OUT, TIM15_CH1, QUADSPI1_BK1_NCS, LPUART1_TX, UCPD1_FRSTX, EVENTOUT | ADC1_IN3, COMP2_INM, OPAMP1_VOUT, WKUP4/LSCO |
| 11 | PA3 | I/O | TIM2_CH4, TIM5_CH4, SAI1_CK1, USART2_RX, TIM15_CH2, QUADSPI1_CLK, LPUART1_RX, SAI1_MCLK_A, EVENTOUT | ADC1_IN4, COMP2_INP, OPAMP1_VINM/OPAMP 1_VINP, OPAMP5_VINM |
| 12 | PA4 | I/O | TIM3_CH2, SPI1_NSS, SPI3_NSS/I2S3_WS, USART2_CK, SAI1_FS_B, EVENTOUT | ADC2_IN17, DAC1_OUT1, COMP1_INM |
| 13 | PA5 | I/O | TIM2_CH1, TIM2_ETR, SPI1_SCK, UCPD1_FRSTX, EVENTOUT | ADC2_IN13, DAC1_OUT2, COMP2_INM, OPAMP2_VINM |
| 14 | PA6 | I/O | TIM16_CH1, TIM3_CH1, TIM8_BKIN, SPI1_MISO, TIM1_BKIN, COMP1_OUT, QUADSPI1_BK1_IO3, LPUART1_CTS, EVENTOUT | ADC2_IN3, DAC2_OUT1, OPAMP2_VOUT |
| 15 | PA7 | I/O | TIM17_CH1, TIM3_CH2, TIM8_CH1N, SPI1_MOSI, TIM1_CH1N, COMP2_OUT, QUADSPI1_BK1_IO2, UCPD1_FRSTX, EVENTOUT | ADC2_IN4, COMP2_INP, OPAMP1_VINP, OPAMP2_VINP |
| 16 | PC4 | I/O | TIM1_ETR, I2C2_SCL, USART1_TX, QUADSPI1_BK2_IO3, EVENTOUT | ADC2_IN5 |
| 17 | PB0 | I/O | TIM3_CH3, TIM8_CH2N, TIM1_CH2N, QUADSPI1_BK1_IO1, HRTIM1_FLT5, UCPD1_FRSTX, EVENTOUT | ADC3_IN12/ADC1_IN15, COMP4_INP, OPAMP2_VINP, OPAMP3_VINP |
| 18 | PB1 | I/O | TIM3_CH4, TIM8_CH3N, TIM1_CH3N, COMP4_OUT, QUADSPI1_BK1_IO0, LPUART1_RTS_DE, HRTIM1_SCOUT, EVENTOUT | ADC3_IN1/ADC1_IN12, COMP1_INP, OPAMP3_VOUT, OPAMP6_VINM |
| 19 | PB2 | I/O | RTC_OUT2, LPTIM1_OUT, TIM5_CH1, TIM20_CH1, I2C3_SMBA, QUADSPI1_BK2_IO1, HRTIM1_SCIN, EVENTOUT | ADC2_IN12, COMP4_INM, OPAMP3_VINM |
| 20 | VREF+ | S | - | VREFBUF_OUT |
| 21 | VDDA | S | - | - |
| 22 | PB10 | I/O | TIM2_CH3, USART3_TX, LPUART1_RX, QUADSPI1_CLK, TIM1_BKIN, HRTIM1_FLT3, SAI1_SCK_A, EVENTOUT | COMP5_INM, OPAMP3_VINM, OPAMP4_VINM |
| 23 | VDD | S | - | - |
| 24 | PB11 | I/O | TIM2_CH4, USART3_RX, LPUART1_TX, QUADSPI1_BK1_NCS, HRTIM1_FLT4, EVENTOUT | ADC12_IN14, COMP6_INP, OPAMP4_VINP, OPAMP6_VOUT |
| 25 | PB12 | I/O | TIM5_ETR, I2C2_SMBA, SPI2_NSS/I2S2_WS, TIM1_BKIN, USART3_CK, LPUART1_RTS_DE, FDCAN2_RX, HRTIM1_CHC1, EVENTOUT | ADC4_IN3/ADC1_IN11, COMP7_INM, OPAMP4_VOUT, OPAMP6_VINP |
| 26 | PB13 | I/O | SPI2_SCK/I2S2_CK, TIM1_CH1N, USART3_CTS, LPUART1_CTS, FDCAN2_TX, HRTIM1_CHC2, EVENTOUT | ADC3_IN5, COMP5_INP, OPAMP3_VINP, OPAMP4_VINP, OPAMP6_VINP |
| 27 | PB14 | I/O | TIM15_CH1, SPI2_MISO, TIM1_CH2N, USART3_RTS_DE, COMP4_OUT, HRTIM1_CHD1, EVENTOUT | ADC4_IN4/ADC1_IN5, COMP7_INP, OPAMP2_VINP, OPAMP5_VINP |
| 28 | PB15 | I/O | RTC_REFIN, TIM15_CH2, TIM15_CH1N, COMP3_OUT, TIM1_CH3N, SPI2_MOSI/I2S2_SD, HRTIM1_CHD2, EVENTOUT | ADC4_IN5/ADC2_IN15, COMP6_INM, OPAMP5_VINM |
| 29 | PC6 | I/O | TIM3_CH1, HRTIM1_EEV10, TIM8_CH1, I2S2_MCK, COMP6_OUT, I2C4_SCL, HRTIM1_CHF1, EVENTOUT | - |
| 30 | PA8 | I/O | MCO, I2C3_SCL, I2C2_SDA, I2S2_MCK, TIM1_CH1, USART1_CK, COMP7_OUT, TIM4_ETR, FDCAN3_RX, SAI1_CK2, HRTIM1_CHA1, SAI1_SCK_A, EVENTOUT | ADC5_IN1, OPAMP5_VOUT |
| 31 | PA9 | I/O | I2C3_SMBA, I2C2_SCL, I2S3_MCK, TIM1_CH2, USART1_TX, OMP5_OUT, TIM15_BKIN, TIM2_CH3, HRTIM1_CHA2, SAI1_FS_A, EVENTOUT | ADC5_IN2, UCPD1_DBCC1 |
| 32 | PA10 | I/O | TIM17_BKIN, USB_CRS_SYNC, I2C2_SMBA, SPI2_MISO, TIM1_CH3, USART1_RX, COMP6_OUT, TIM2_CH4, TIM8_BKIN, SAI1_D1, HRTIM1_CHB1, SAI1_SD_A, EVENTOUT | UCPD1_DBCC2, PVD_IN |
| 33 | PA11 | I/O | SPI2_MOSI/I2S2_SD, TIM1_CH1N, USART1_CTS, COMP1_OUT, FDCAN1_RX, TIM4_CH1, TIM1_CH4, TIM1_BKIN2, HRTIM1_CHB2, EVENTOUT | USB_DM |
| 34 | PA12 | I/O | TIM16_CH1, I2SCKIN, TIM1_CH2N, USART1_RTS_DE, COMP2_OUT, FDCAN1_TX, TIM4_CH2, TIM1_ETR, HRTIM1_FLT1, EVENTOUT | USB_DP |
| 35 | VDD | S | - | - |
| 36 | PA13 | I/O | SWDIO-JTMS, TIM16_CH1N, I2C4_SCL, I2C1_SCL, IR_OUT, USART3_CTS, TIM4_CH3, SAI1_SD_B, EVENTOUT | - |
| 37 | PA14 | I/O | SWCLK-JTCK, LPTIM1_OUT, I2C4_SMBA, I2C1_SDA, TIM8_CH2, TIM1_BKIN, USART2_TX, SAI1_FS_B, EVENTOUT | - |
| 38 | PA15 | I/O | JTDI, TIM2_CH1, TIM8_CH1, I2C1_SCL, SPI1_NSS, SPI3_NSS/I2S3_WS, USART2_RX, UART4_RTS_DE, TIM1_BKIN, FDCAN3_TX, HRTIM1_FLT2, TIM2_ETR, EVENTOUT | - |
| 39 | PC10 | I/O | TIM8_CH1N, UART4_TX, SPI3_SCK/I2S3_CK, USART3_TX, HRTIM1_FLT6, EVENTOUT | - |
| 40 | PC11 | I/O | HRTIM1_EEV2, TIM8_CH2N, UART4_RX, SPI3_MISO, USART3_RX, I2C3_SDA, EVENTOUT | - |
| 41 | PB3 | I/O | JTDO-TRACESWO, TIM2_CH2, TIM4_ETR, UCPD1_CRS_SYNC, TIM8_CH1N, SPI1_SCK, SPI3_SCK/I2S3_CK, USART2_TX, TIM3_ETR, FDCAN3_RX, HRTIM1_SCOUT, HRTIM1_EEV9, SAI1_SCK_B, EVENTOUT | - |
| 42 | PB4 | I/O | JTRST, TIM16_CH1, TIM3_CH1, TIM8_CH2N, SPI1_MISO, SPI3_MISO, USART2_RX, UART5_RTS_DE, TIM17_BKIN, FDCAN3_TX, HRTIM1_EEV7, SAI1_MCLK_B, EVENTOUT | UCPD1_CC2 |
| 43 | PB5 | I/O | TIM16_BKIN, TIM3_CH2, TIM8_CH3N, I2C1_SMBA, SPI1_MOSI, SPI3_MOSI/I2S3_SD, USART2_CK, I2C3_SDA, FDCAN2_RX, TIM17_CH1, LPTIM1_IN1, SAI1_SD_B, HRTIM1_EEV6, UART5_CTS, EVENTOUT | - |
| 44 | PB6 | I/O | TIM16_CH1N, TIM4_CH1, TIM8_CH1, TIM8_ETR, USART1_TX, COMP4_OUT, FDCAN2_TX, TIM8_BKIN2, LPTIM1_ETR, HRTIM1_SCIN, HRTIM1_EEV4, SAI1_FS_B, EVENTOUT | UCPD1_CC1 |
| 45 | PB7 | I/O | TIM17_CH1N, TIM4_CH2, I2C4_SDA, I2C1_SDA, TIM8_BKIN, USART1_RX, COMP3_OUT, TIM3_CH4, LPTIM1_IN2, FMC_NL, HRTIM1_EEV3, UART4_CTS, EVENTOUT | - |
| 46 | PB8-BOOT0 | I/O | TIM16_CH1, TIM4_CH3, SAI1_CK1, I2C1_SCL, USART3_RX, COMP1_OUT, FDCAN1_RX, TIM8_CH2, TIM1_BKIN, HRTIM1_EEV8, SAI1_MCLK_A, EVENTOUT | - |
| 47 | PB9 | I/O | TIM17_CH1, TIM4_CH4, SAI1_D2, I2C1_SDA, IR_OUT, USART3_TX, COMP2_OUT, FDCAN1_TX, TIM8_CH3, TIM1_CH3N, HRTIM1_EEV5, SAI1_FS_A, EVENTOUT | - |
| 48 | VDD | S | - | - |

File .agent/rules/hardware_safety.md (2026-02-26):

---
trigger: always_on
---

---
description: Reglas de seguridad críticas para el desarrollo de firmware en SCLF Gripper (STM32 + DRV8316). Activar siempre.
globs: "**/*.{cpp,h,ini}"
always_on: true
---

# Reglas de Seguridad de Hardware

1. **Prohibición de Bloqueo:** Jamás uses `HAL_Delay`, `delay()` o `while()` en el bucle `loopFOC()`.
2. **Validación de Pines:** Antes de cualquier implementación de código, verifica la asignación de pines contra el archivo `hardware/*.kicad_sch`.
3. **Manejo de Timers:** Prioriza TIM1, TIM8 o TIM20 para PWM. Verifica en el datasheet del STM32G474CEU6 que no existan conflictos de DMA.

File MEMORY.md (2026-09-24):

# MEMORY.md — SCLF Gripper Firmware
> Proiektuaren egoera iraunkorra garapen saioen artean.
> **Fitxategi hau eguneratu saio produktibo bakoitzaren amaieran.**
> IA agenteak fitxategi hau irakurri behar du saio bakoitzaren hasieran.

---

## Proiektuaren Uneko Egoera

| Eremua | Balioa |
|---|---|
| **Fase aktiboa** | Prototipo berriaren balioztapena |
| **Azken eguneraketa** | 2026-04-15 |
| **Konpilazioa** | ✅ Egiaztatuta (Ondo konpilatzen du) |
| **ST-Link Flasheatzea** | ✅ Funtzionatzen du (upload OK) |
| **LED Heartbeat** | ✅ Egiaztatuta (PC6 / D4 keinuka) |
| **Encoder MT6701** | ✅ Egiaztatuta (Ondo dabil 24V gabe ere) |
| **DRV8316 SPI** | ✅ Egiaztatuta (STATUS2: 0x60, SPI komunikazioa OK) |
| **Motorra probatuta** | ✅ Egiaztatuta (Begizta Irekian / Open loop OK) |

---

## Garapen Ingurunea

| Eremua | Balioa |
|---|---|
| IDE | Antigravity (Windsurf/VSCode fork-a) |
| PlatformIO | ✅ Instalatuta |
| cpptools | ✅ Instalatuta |
| cortex-debug | ✅ Instalatuta |
| Garatzailearen OS | Windows |
| ST-Link bertsioa | ST-Link V2 (klona) ✅ Funtzionatzen du |
| Board (platformio.ini) | `nucleo_g474re` |

### `.vsix` deskarga estekak
- cpptools: https://github.com/microsoft/vscode-cpptools/releases
- platformio-ide: https://github.com/platformio/platformio-vscode-ide/releases

---

## Egiaztatutako Hardwarea

### Eskematikoa
- **Fitxategia:** `SCLF_Gripper.kicad_sch` ✅ Analizatuta
- **PCB:** `SCLF_Gripper.kicad_pcb` ✅ Eskuragarri
- **BOM:** `SCLF_Gripper_bom.csv` ✅ Analizatuta

### Eskematikoko aurkikuntza kritikoak
1. DRV8316-ren `nFAULT` **EZ DAGO KONEKTATUTA** STM32-ra — soilik tokiko pull-up
2. DRV8316-ren `DRVOFF` **GND**-ra konektatuta — driverra beti gaituta
3. MAX3485-en `DE/RE` = **PB9** (`RS485_DIR`)
4. SPI1 partekatua: DRV8316 (CS=PC4) + MT6701 (CS=PA4) bus berean PB3/PB4/PB5
5. PB6, PB7, PA15 izendatutako net gisa agertzen dira baina **funtziorik gabe** — erreserbatuta

---

## Baieztatutako Pin Map-a

| STM32 Pin | Net | Funtzioa |
|---|---|---|
| PA0 | CURA | Phase A current sense ADC |
| PA1 | CURB | Phase B current sense ADC |
| PA2 | CURC | Phase C current sense ADC (test pad) |
| PA4 | ENC_CS | MT6701 encoder SPI CS |
| PA5 | ENC_CLK | MT6701 encoder SPI CLK |
| PA6 | ENC_SDO | MT6701 encoder SPI MISO |
| PA8 | CH | Phase C High PWM |
| PA9 | BH | Phase B High PWM |
| PA10 | AH | Phase A High PWM |
| PA11 | D- | USB D- |
| PA12 | D+ | USB D+ |
| PA13 | SWDIO | SWD programming |
| PA14 | SWCLK | SWD programming |
| PB3 | DRV_CLK | DRV8316 SPI CLK (SPI1) |
| PB4 | DRV_MISO | DRV8316 SPI MISO (SPI1) |
| PB5 | DRV_MOSI | DRV8316 SPI MOSI (SPI1) |
| PB8 | BOOT0 | Boot button (DFU mode) |
| PB9 | RS485_DIR | RS-485 DE/RE direction |
| PB11 | VSENS | DC bus voltage sense |
| PB13 | AL | Phase A Low PWM |
| PB14 | BL | Phase B Low PWM |
| PB15 | CL | Phase C Low PWM |
| PC4 | DRV_CS | DRV8316 SPI CS |
| PC6 | LED_PC6 | Status LED |
| PC10 | RS485_TX | RS-485 UART TX |
| PC11 | RS485_RX | RS-485 UART RX |
| PF0 | XIN | Crystal 16 MHz OSC_IN |
| PF1 | XOUT | Crystal 16 MHz OSC_OUT |
| PG10 | RST | Reset button / SWD RST |

---

## Motorraren Parametroak

> ⚠️ Bete erabiliko den motor zehatza ezagutzen denean.

| Parametroa | Balioa | Egoera |
|---|---|---|
| Fabrikatzailea/Modeloa | GM3506 | ✅ Egiaztatuta |
| Mota | BLDC / PMSM (24N22P) | ✅ Egiaztatuta |
| Polo pare kopurua | 11 | ✅ Egiaztatuta |
| Fase-erresistentzia (Ω) | ? | ⏳ Zain |
| Fase-induktantzia (mH) | ? | ⏳ Zain |
| Korronte izendatua (A) | ? | ⏳ Zain |
| Korronte-gailurra (A) | ? | ⏳ Zain |
| Abiadura maximoa (rpm) | ~35 rad/s (lazo itxian 2V-rekin) | ✅ Egiaztatuta |

---

## Kalibratutako FOC Parametroak

> Bete `motor.initFOC()` lehen aldiz exekutatu ondoren.

| Parametroa | Balioa | Data |
|---|---|---|
| `zero_electric_angle` | 1.1098 rad | 2026-05-05 |
| `sensor_direction` | -1 (CCW) | 2026-05-05 |
| PWM frequency (kHz) | ? | — |
| FOC loop time (µs) | ? | — |

---

## PID Irabazi Aktiboak

> Balio kontserbadoreekin hasi. Hemen eguneratu aldatzen diren bakoitzean.

### Torque / Current loop
| Irabazia | Balioa | Oharrak |
|---|---|---|
| KP | 0.5 | Hasierakoa (kontserbadorea) |
| KI | 10.0 | Hasierakoa (kontserbadorea) |
| KD | 0.0 | — |

### Velocity loop
| Irabazia | Balioa | Oharrak |
|---|---|---|
| KP | 2.0 | Bench test-erako doikuntza (marruskadura estatikoa gainditzeko) |
| KI | 0.0 | Integralik gabe hasierako tuning-ean windup ekiditeko |
| KD | 0.0 | — |

### Position loop
| Irabazia | Balioa | Oharrak |
|---|---|---|
| KP | 5.0 | Bench test-erako doikuntza lehenetsia |
| KI | 0.0 | — |
| KD | 0.0 | — |

---

## Segurtasun Muga Aktiboak

| Parametroa | Uneko balioa | Baimendutako maximoa |
|---|---|---|
| `motor.voltage_limit` | 2.0 V | — (motor errealarekin doitu) |
| `motor.current_limit` | 1.0 A | — (motor errealarekin doitu) |
| `motor.velocity_limit` | 10.0 rad/s | — (motor errealarekin doitu) |

---

## Egiaztatutako Liburutegi Bertsioak

| Liburutegia | Bertsioa | Egoera |
|---|---|---|
| SimpleFOC | ^2.3.3 | ✅ Probatuta (Konpilazioa OK) |
| STM32duino (platform) | latest | ✅ Probatuta (Konpilazioa OK) |
| cpptools | 1.23.6 | ✅ Instalatuta |
| platformio-ide | 3.3.4 | ✅ Instalatuta |

---

## Komando Gida (Commander USB)

| Komandoa | Deskribapena | Adibidea |
|---|---|---|
+| `M` | Motorraren egoera orokorra | `M` |
+| `M<balioa>` | Setpoint-a ezarri (rad/s edo rad) | `M1.5` |
+| `ME<0/1>` | Motorra desgaitu/gaitu | `ME0`, `ME1` |
+| `MC<0/1/2/3>` | Kontrol modua aldatu (0:Voltage, 1:Torque, 2:Vel, 3:Pos) | `MC2` |
+| `MV<P/I/D>` | Abiadura PID-a doitu | `MVP0.1`, `MVI1.0` |
+| `MP<P/I/D>` | Posizio PID-a doitu | `MPP5.0` |
+| `T<0/1>` | Telemetria automatikoa desgaitu/gaitu | `T1`, `T0` |
+| `?` | Laguntza orokorra | `?` |

---

## Garapen Saioak

### 2026-02-25 — Hasierako saioa
- ✅ KiCad eskematiko osoa analizatuta
- ✅ STM32 pin guztiak egiaztatuta eskematikoarekin
- ✅ Sortuak: `SRS.md`, `AGENT.md`, `TASKS.md`, `RULES.md`, `MEMORY.md`, `pins.h`, `platformio.ini`
- ⏳ Zain: PlatformIO instalatzea Antigravityn eta lehen konpilazioa egiaztatzea

### 2026-02-26 — Euskera Garapena eta Konpilazioa Egiaztatzea
- ✅ Proiektuaren dokumentazioa Euskerara itzulia (garapena Euskeraz jarraitzeko).
- ✅ README-ak hiru hizkuntzatan egituratuta (EN, EU, ES).
- ✅ Firmwarea ondo konpilatzen dela egiaztatuta PlatformIO-ren bidez azken mendetasunekin.

### 2026-03-07 — STM32 Flasheatzea eta Debug Saioa
- ✅ ST-Link V2 klona erabili y upload OpenOCD funcionan OK
- ✅ LED Heartbeat testa y USB CDC Serial (HSI48 flag) OK
- ✅ MT6701 SPI kodea kargatua (`fase1_1_mt6701_test`). 💡 **Aurkikuntza:** 3.3V-tik dabil, ez du 24V behar!
- ✅ SPIClass MOSI fix-a: `NC` ordez `PA7`. Board aldaketa: `nucleo_g474re`.
- ✅ RS-485 Driver inplementazioa (`fase1_4_rs485_ping`). MAX3485 Half-Duplex funtzionamendua baliozkotua SIMULATZAILE bidez (RX injectatuz USB bidez).
- ⚠️ **BLOKEATUTA:** Fase 1.2 (SPI driver) eta Fase 1.3/2 (Motor testa) 24V elikadura eta *pogo pins* iritsi arte ezin dira probatu.

### 2026-04-15 — Prototipo berriaren Migrazioa eta Garbiketa
- ✅ Pinout-a eguneratu da prototipo berrirako (`DRV-uC_connections.md` eta `pins.h`).
- ✅ Garbiketa orokorra: bertsio labelak (v1.0) kenduta.
- ✅ TASKS.md-n testak hasieratu dira balioztapen berrirako.
- ✅ **Fase 1.1 (MT6701)**: Prototipo berrian balioztatua. Raw Counts (0-16383) eta angelu metatuak ondo.
- ✅ **Fase 1.2 (DRV8316 SPI)**: Prototipo berrian balioztatua. SPI komunikazioa finkatua. `STATUS2: 0x60` (Buck fault) persistentea, v1.0-n bezala.
- ✅ **Fase 1.3 (Motorra)**: Prototipo berrian balioztatua. Motorra begizta irekian (open loop) biratzen du 24V-ekin. 
- 💡 **Oharra**: Hasierako "pivoteoa" motorreko kable baten deskonexioagatik zen, ez hardware arazoagatik.
- ⏳ Zain: RS485 komunikazio probak (Fase 1.4).

### 2026-04-22 — Fase 4 (USB VCP) Implementazioa
- ✅ `VCPManager` osagaia sortua (`src/comms/VCP.h/.cpp`):
    - SimpleFOC-en `Commander` interfazea kapsulatzen du.
    - Telemetria ez-blokeatzailea implementatua (`T1` aginduarekin aktibatzen da).
    - Motorraren aginduak (`M`) zuzenean kudeatzen ditu.
- ✅ `examples/phase4_USB_VCP` sortua eta balioztatua (kode egitura).
- ✅ `platformio.ini` eguneratua `test_usb_vcp` ingurunearekin.
- 💡 **Oharra**: USB CDC-a (VCP) doikuntzak denbora errealean egiteko (tuning) bideratuta dago batez ere.

### 2026-04-22 — Fase 5 (Fault Manager) Implementazioa
- ✅ `FaultManager` osagaia guztiz operatiboa:
    - MT6701 encoder erroreak detektatzen ditu (zarata-iragazkiarekin).
    - DRV8316 driver akatsak monitorizatzen ditu.
    - **Stall detekzioa**: 1s-ko blokeo mekanikoaren ondoren motorra desgaitzen du.
- ✅ `VCPManager` eguneratua komando pertsonalizatuak onartzeko.
- ✅ `F` komandoa gehitu da akatsak garbitzeko eta sistema rearmatzeko.
- ✅ Prototipoan balioztatua: motorra desgaitzen da blokeatzean eta monitoretik errorea bidaltzen du.

### 2026-04-22 — Fase 6 (Persistence) Implementazioa
- ✅ `FlashConfig` osagaia martxan STM32G474-rako (HAL_FLASH erabiliz).
- ✅ Biltegiratzea Banku 1eko azken orrialdean (**0x0803F800**) Dual-Bank arazoak ekiditeko.
- ✅ CRC32 bidezko integritatea eta Balio Magiko bidezko balioztatzea.
- ✅ Komandoak: `S` (Gorde uneko konfigurazioa) eta `R` (Fabrikako reset).
- ✅ Parametroak: PIDak (vel/pos), mugak (volt/curr/vel) eta FOC kalibrazioa.

### 2026-05-05 — Fase 7.1 (Motor-Encoder Lerrokatzea)
- ✅ `initFOC()` exekuzio egonkorra: `ZEA = 1.1098`, `dir = -1`.
- ✅ Lazo itxiko Torque modua (`MC0`) 35 rad/s abiadurarekin Uq=2V-tan.
- ✅ Lazo itxiko Abiadura modua (`MC1`) egonkorra PID P=2 y I=0 doikuntzekin.
- ✅ MT6701-ren `shaft_angle` biraketa askotarako egokia dela baieztatu da.
- ✅ STALL detekzio optimizatua `highEffort` flag-aren bitartez epe laburreko gainkargak iragazteko.

### 2026-09-24 — Fase 3.3 (UR Robot / URCap RS-485 Integrazioa)
- ✅ RS-485 bidezko komunikazioa balioztatuta Universal Robots URSim eta URCap-ekin (115200 baud, J3 konektorea).
- ✅ `PING` eta `EN` komandoek berehalako erantzuna eta feedback bisuala (LED) eskaintzen dute.
- ✅ `V` (abiadura), `P` (posizioa) eta `?S` (egoera) komandoak zuzen kudeatzen dira modu ez-blokeatzailean.
- ✅ Agiriak hiru hizkuntzetan (Euskera, Gaztelania, Ingelesa) osatu dira `examples/phase3_3_ur_rs485/README.md`-n.

---

## Oharrak eta Erabakiak (Zain)

- [ ] Baieztatu gripperrarekin erabiliko den BLDC motorraren eredu zehatza
- [ ] Baieztatu PB6/PB7/PA15 funtziorik daukaten azken diseinuan ala erreserbak diren
- [ ] Erabaki gailuaren RS-485 IDa hardware bidez (DIP switch?) ala software komando bidez konfiguratzen den
- [ ] Erabaki DRV8316 STATUS-aren polling maiztasuna (loop bakoitzeko? 10 ms-ro?)

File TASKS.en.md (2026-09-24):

# TASKS.md — SCLF Gripper Firmware
> Complete project backlog, organized by development phases.
> Status: `[ ]` pending · `[~]` in progress · `[x]` completed · `[!]` blocked

---
> 📢 **CURRENT STATUS AND NEXT STEPS**
> **Phases 4, 5 and 6 COMPLETED.** ✅
> **Phase 7.1 (Motor-Encoder Alignment and Base Tuning) COMPLETED.** ✅
> The next step is **PHASE 7.2 (PID Tuning with Load)** or **PHASE 7.3 (Kinematics)**.
---

---

## PHASE 0 — Environment and Scaffolding [x]
> Goal: project compiles and blinks an LED. Nothing else.

- [x] Create `platformio.ini` with target `nucleo_g474re`, 170 MHz, ST-Link
- [x] Create `src/config/pins.h` verified against the KiCad schematic
- [x] Create `SRS.md`, `AGENT.md`, `RULES.md`, `TASKS.md`, `MEMORY.md`
- [x] Install PlatformIO in Antigravity via `.vsix` (cpptools + platformio-ide)
- [x] Install `cortex-debug` extension for ST-Link debugging
- [x] Verify `pio run` compiles without errors
- [x] Run `pio run --target upload` and confirm the ST-Link detects the board
- [x] Blink `PIN_LED` (PC6/D4) — pre-test `fase0_led_heartbeat` ✅
- [x] Confirm the USB VCP Serial Monitor works (`Serial.begin()`) ✅

---

## PHASE 1 — Basic Drivers [x]
> Goal: read the encoder, read current, communicate via RS-485. No FOC yet.

### 1.1 MT6701 Encoder Driver [x]
- [x] Create `src/encoder/MT6701.h` — Public API:
  - `bool begin()` — initializes SPI (PA5=CLK, PA6=SDO, PA7=MOSI dummy)
  - `float getAngleRad()` — returns angle in radians [0, 2π)
  - `uint16_t getRawCounts()` — returns raw 14-bit value [0–16383]
  - `bool isOk()` — verifies SPI read is valid
- [x] Create `src/encoder/MT6701.cpp` — implementation
- [x] Create `examples/fase1_1_mt6701_test/main.cpp` — manual test
- [x] Manual test: print angle/raw via VCP (Works with ST-Link 3.3V)
- [x] Verify encoder: The LED changes speed and USB shows raw=0-16383
- [x] Verify correct wrap-around (16383 → 0 without abrupt jump in `getAngleRad`)
- [x] Implement multi-turn tracking (accumulated angles > 360º)
- [x] Implement relative zero initialization on startup

### 1.2 DRV8316 SPI Driver [x]
- [x] Create `src/motor/DRV8316.h` — Public API:
  - `bool begin()` — initializes SPI (PC4/PB3/PB4/PB5) and configures registers
  - `uint16_t readRegister(uint8_t addr)`
  - `void writeRegister(uint8_t addr, uint16_t value)`
  - `bool hasFault()` — reads STATUS1/STATUS2 via SPI
  - `uint8_t getFaultCode()` — returns error code
  - `void clearFaults()`
- [x] Create `src/motor/DRV8316.cpp`
- [x] Read and verify DRV8316 DEVICE_ID register on startup
- [x] Print STATUS1 and STATUS2 via VCP
- [x] **IMPORTANT:** There is no nFAULT pin on the STM32. All faults are detected via SPI polling.

### 1.3 Open-Loop Velocity Control [x]
- [x] Create `examples/fase1_3_open_loop_v_control/main.cpp`
- [x] Configure 6-PWM mode (AH, AL, BH, BL, CH, CL)
- [x] Open-loop velocity control rotation — **Validated on v2.0 hardware (24V)**

### 1.4 RS485 Ping-Pong Test [x]
- [x] Validate `examples/fase1_4_rs485_ping/main.cpp`
- [x] Ping-Pong test (VCP and external bus)

### 1.5 Current Sense [x]
- [x] Create `src/motor/CurrentSense.h/.cpp` — wrapper for SimpleFOC's `InlineCurrentSense`
- [x] Calibrate current offset at zero (motor stopped, no current)
- [x] Print currents from the 3 phases via VCP with stopped/blocked motor

---

## PHASE 2 — Basic FOC [x]
> Goal: motor spins in open-loop and then basic closed-loop using SimpleFOC.

### 2.1 FOC Open-Loop [x]
- [x] Add `askuric/Simple FOC @ ^2.3.3` to `lib_deps` in `platformio.ini`
- [x] Create `src/motor/MotorController.h/.cpp` — SimpleFOC wrapper
- [x] Validate rotation in `examples/fase2_1_foc_open_loop/main.cpp`
- [x] Verify motor spins without excessive noise (tweak voltage limit)

### 2.2 FOC Closed-Loop [x]
- [x] Implement aligned and velocity control in `examples/fase2_2_foc_closed_loop/main.cpp`
- [x] Test torque mode: `motor.controller = MotionControlType::torque`
- [x] Tune initial PID gains (KP, KI, KD) for each loop

---

## PHASE 3 — RS-485 Protocol
> Goal: the gripper obeys bus commands from the robot.

### 3.1 Basic Protocol (Ping / ID / Info) [x]
- [x] Design and implement command parser in `src/comms/RS485.cpp`:
  ```
  <id>:<cmd>:<value>\n
  ```
- [x] Implement basic commands:
  - [x] `PING` — Verify bus connection (`PONG` response)
  - [x] `?A` — get angle (rad) [Placeholder value in test]
- [x] Implement multi-device addressing (configurable ID)
- [x] Roundtrip test: send command from PC, verify valid response ✅
- [x] Added `delayMicroseconds(200)` in `RS485.cpp` to prevent "clipping" error ✅

### 3.2 Control Commands [x]
- [x] Implement advanced commands (T, V, P, M, EN, DIS, KP, KI, KD, ?V, ?I, ?S) ✅
- [x] Add shorthand commands (V5, P1, A, E, D) ✅
- [x] Roundtrip test and improved visual feedback (VCP Mirror) ✅
- [ ] Timing test: measure TX→RX latency on RS-485 bus

### 3.3 UR Robot / URCap RS-485 Integration [x] ✅
- [x] Validate connection and communication with the UR robot via J3 connector (115200 baud) ✅
- [x] Design the URCap structure and communication daemon (XML-RPC server) ✅
- [x] Test position (P), speed (V), force (T) and status (?S) control using URScript (validated with URSim + URCap) ✅

---

## PHASE 4 — USB VCP & Commander
> Goal: live tuning from PC over USB.

- [x] Activate `SimpleFOCDebug::enable(&Serial)` — telemetry via USB VCP ✅
- [x] Create `src/comms/VCP.cpp` — SimpleFOC Commander: ✅
  - [x] Register motor, PID gains, control mode
  - [x] Real-time telemetry streaming: angle, velocity, current, target
- [x] Verify VCP does not block the FOC loop (use circular buffers or DMA) ✅
- [x] Document available Commander commands in `MEMORY.md` ✅

---

## PHASE 5 — Fault Manager
> Goal: the gripper never self-destructs.

- [x] Create `src/faults/FaultManager.h/.cpp`: ✅
  - [x] `void update()` — call every loop, poll DRV8316 STATUS via SPI ✅
  - [x] `bool hasFault()` — returns true if any active fault exists ✅
  - [x] `FaultCode getActiveFault()` — enum: OVERCURRENT, ENCODER_ERROR, STALL, DRV_FAULT ✅
  - [x] `void triggerSafeState()` — calls `motor.disable()` in < 1 ms ✅
  - [x] `void reportFault(FaultCode)` — reports code via RS-485 and VCP ✅
- [x] Detect stall: velocity < threshold for > N ms with current > limit ✅
- [x] Detect encoder error: `MT6701::isOk()` returns false (noise filter added) ✅
- [x] Fault test: short-circuit a phase briefly and verify response (validated with mechanical block) ✅
- [x] Verify `triggerSafeState()` occurs in < 1 ms after detection ✅

---

## PHASE 6 — Persistence & Configuration
> Goal: parameters survive power cycles and resets.

- [x] Define `Config` struct in flash (dedicated STM32G474 sector): ✅
  - [x] `zero_electric_angle` (float) ✅
  - [x] `sensor_direction` (int) ✅
  - [x] `device_id` (uint8_t) ✅
  - [x] `pid_gains[3][3]` (float[loop][kp/ki/kd]) ✅
  - [x] `control_mode` (uint8_t) ✅
  - [x] CRC32 validation (XOR Checksum implemented) ✅
- [x] Implement `src/config/FlashConfig.h/.cpp`: ✅
  - [x] `bool load()` — reads config from flash, validates CRC ✅
  - [x] `void save()` — writes config to flash using HAL_FLASH_Program ✅
  - [x] `void resetDefaults()` — applies default values ✅
- [x] On startup: if flash config is valid, load parameters and skip recalibration ✅
- [x] RS-485 commands to read/write config and perform factory reset (integrated via Commander 'S' and 'R') ✅

---

## PHASE 7 — Advanced FOC Tuning
> Goal: Full FOC with encoder and current sense. Motor responds to targets.

### 7.1 Motor-Encoder Alignment (Bench Test) [x]
- [x] Connect MT6701 encoder to SimpleFOC: `MagneticSensorSPI encoder(PIN_ENC_CS, 14, 0x3FFF)`
- [x] Run `motor.initFOC()` — automatic electrical alignment
  - Capture and save `motor.zero_electric_angle` and `motor.sensor_direction` to flash
- [x] Test torque mode: `motor.controller = MotionControlType::torque`
- [x] Test closed-loop velocity with encoder and tune base PID
- [x] Test closed-loop position with encoder
- [x] Save base configuration to Flash to skip physical recalibration

### 7.2 PID Tuning with Load
- [ ] Mount the motor on the gripper's mechanical structure
- [ ] Tune PID gains (KP, KI, KD) for each loop with real inertia
- [ ] Verify `motor.loopFOC()` runs at ≥ 10 kHz without blocking
- [ ] Connect `InlineCurrentSense` and activate FOC with real currents

### 7.3 Gripper Kinematics
- [ ] Convert motor radians to gripper opening in millimeters
- [ ] Implement software limits (max/min opening)
- [ ] Implement grip control via torque/current limiting

---

## PHASE 8 — Tests & Validation
> Goal: firmware is reliable and stable.

- [ ] Create tests in `test/` using PlatformIO Unity framework:
  - `test_pid.cpp` — verify PID responds properly to setpoints
  - `test_rs485_parser.cpp` — verify parser with valid/invalid frames
  - `test_angle_wrap.cpp` — verify 16383→0 wrap generates no gaps
  - `test_fault_codes.cpp` — verify fault codes decode correctly
- [ ] Run `pio test` and check for 0 failures
- [ ] Measure and document loop times in `MEMORY.md`
- [ ] Measure flash/RAM consumption, ensure < 80% limit

---

## PHASE 9 — Final Documentation
- [ ] Update `MEMORY.md` with final starting PID parameters
- [ ] Update `MEMORY.md` with electric offset and encoder direction
- [ ] Write `README.md` for end users (connections, configuration, RS-485 commands)
- [ ] Create a State Machine diagram (Mermaid)
- [ ] Annotate verified versions of SimpleFOC and STM32duino

---

## Backlog / Future Ideas
> No date. Evaluate once main phases are complete.

- [ ] CAN bus support (STM32G474 has FDCAN — needs external hardware)
- [ ] Trapezoidal motion profile (smooth acceleration/deceleration)
- [ ] PID Auto-tuning via step response
- [ ] OTA firmware updates over RS-485 (custom bootloader)
- [ ] Live visual PC Dashboard

---

## Technical Decisions Log

| Date | Decision | Reason |
|---|---|---|
| 2026-02-25 | DRV8316 nFAULT not connected to STM32 | Verified in KiCad schematic |
| 2026-02-25 | DRV8316 DRVOFF to permanent GND | Driver always enabled by hardware |
| 2026-02-25 | Fault detection via SPI polling, not GPIO IRQ | No available pin for nFAULT |
| 2026-02-25 | SPI shared between DRV8316 (PC4 CS) & MT6701 (PA4 CS) | PB3/PB4/PB5 are the SPI1 bus |
| 2026-02-25 | RS-485 half-duplex with PB9 as DE/RE | Confirmed in schematic |
| 2026-03-07 | Board changed from `genericSTM32G474CE` to `nucleo_g474re` | `generic` does not support Arduino framework |
| 2026-03-07 | SPIClass MOSI: use `PA7` instead of `NC` | `NC` blocks SPI initialization |
| 2026-03-07 | ST-Link 3.3V powers MCU and Encoder | **MT6701 works without 24V supply**. Only the driver needs it. |
| 2026-03-07 | **USB CDC Fix:** Added `SystemClock_Config` in `main.cpp` | STM32G4 requires enabling HSI48 for the USB peripheral |
| 2026-03-07 | RS-485 Half-Duplex testing challenge | MAX3485 blocks RX during TX. Created `simulateRx()` test branch to bypass. |
| 2026-03-14 | **HARDWARE BUG v1: U1 Pin 23 to D5** | Driver nSLEEP was powered down. Will be fixed in v2. |
| 2026-03-24 | **WAITING FOR HARDWARE V2** | We have updated pins and are blocked waiting for PCB. |
| 2026-04-21 | **REORGANIZATION: Advanced FOC postponed** | Decided to wait for gripper assembly. Moved comm and safety phases forward. |
| 2026-04-22 | **Phase 4: USB VCP implemented** | Created `VCPManager` to manage Commander and non-blocking telemetry. |

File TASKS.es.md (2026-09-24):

# TASKS.md — Firmware del SCLF Gripper
> Backlog completo del proyecto, organizado por fases de desarrollo.
> Estado: `[ ]` pendiente · `[~]` en progreso · `[x]` completado · `[!]` bloqueado

---
> 📢 **ESTADO ACTUAL Y PRÓXIMOS PASOS**
> **Fase 4, 5 y 6 COMPLETADAS.** ✅
> **Fase 7.1 (Alineación Motor-Encoder y Tuning base) COMPLETADA.** ✅
> El siguiente paso es la **FASE 7.2 (Ajuste PID con Carga)** o la **FASE 7.3 (Cinemática)**.
---

---

## FASE 0 — Entorno y Scaffolding [x]
> Objetivo: proyecto compila y hace parpadear un LED. Nada más.

- [x] Crear `platformio.ini` con target `nucleo_g474re`, 170 MHz, ST-Link
- [x] Crear `src/config/pins.h` verificado contra el esquemático KiCad
- [x] Crear `SRS.md`, `AGENT.md`, `RULES.md`, `TASKS.md`, `MEMORY.md`
- [x] Instalar PlatformIO en Antigravity via `.vsix` (cpptools + platformio-ide)
- [x] Instalar extensión `cortex-debug` para debug con ST-Link
- [x] Verificar que `pio run` compila sin errores
- [x] Hacer `pio run --target upload` y confirmar que el ST-Link detecta la placa
- [x] Hacer parpadear `PIN_LED` (PC6/D4) — pre-test `fase0_led_heartbeat` ✅
- [x] Confirmar que el monitor serie USB VCP funciona (`Serial.begin()`) ✅

---

## FASE 1 — Drivers Básicos [x]
> Objetivo: leer encoder, leer corriente, hablar por RS-485. Sin FOC todavía.

### 1.1 MT6701 Encoder Driver [x]
- [x] Crear `src/encoder/MT6701.h` — API pública:
  - `bool begin()` — inicializa SPI (PA5=CLK, PA6=SDO, PA7=MOSI dummy)
  - `float getAngleRad()` — devuelve ángulo en radianes [0, 2π)
  - `uint16_t getRawCounts()` — devuelve valor crudo 14-bit [0–16383]
  - `bool isOk()` — comprueba que la lectura SPI es válida
- [x] Crear `src/encoder/MT6701.cpp` — implementación
- [x] Crear `examples/fase1_1_mt6701_test/main.cpp` — test manual
- [x] Test manual: imprimir ángulo/raw por VCP (Funciona con ST-Link 3.3V)
- [x] Verificar encoder: El LED cambia velocidad y USB muestra raw=0-16383
- [x] Verificar wrap-around correcto (16383 → 0 sin salto brusco en `getAngleRad`)
- [x] Implementar seguimiento de vueltas (ángulos acumulados > 360º)
- [x] Implementar inicialización de cero relativo al encendido
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

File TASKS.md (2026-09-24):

# TASKS.md — SCLF Gripper Firmware
> Proiektuaren backlog osoa, garapen-faseka antolatuta.
> Egoera: `[ ]` egiteke · `[~]` martxan · `[ ]` amaituta · `[!]` blokeatuta

---
> 📢 **UNEKO EGOERA ETA HURRENGO URRATSAK**
> **Fase 4, 5 eta 6 AMAITUTA.** ✅
> **7.1 Fasea (Motor-Encoder Lerrokatzea eta Tuning-a) AMAITUTA.** ✅
> Hurrengo urratsa **7.2 FASEA (PID Doikuntza Kargarekin)** edo **7.3 FASEA (Zinematika)** da.
---

---
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

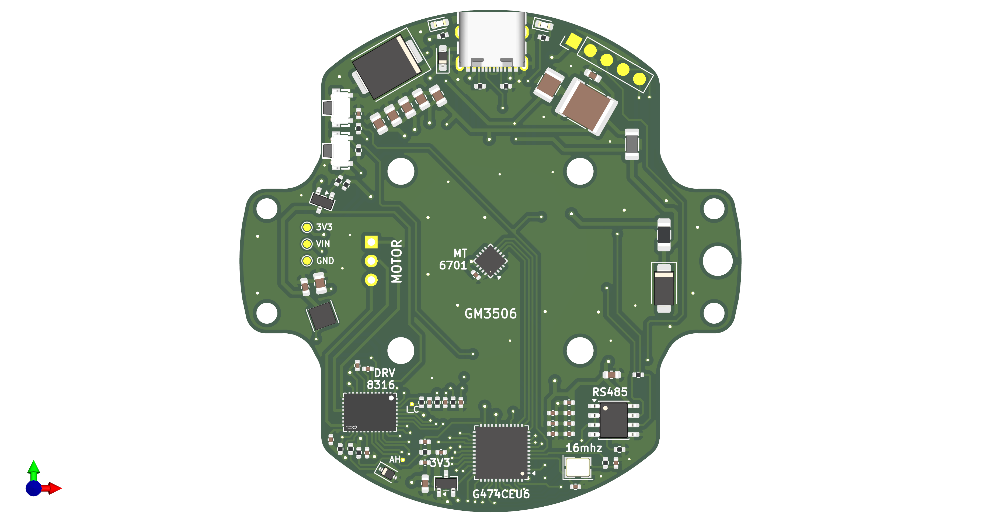
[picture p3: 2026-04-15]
images/Gripper_Top.png

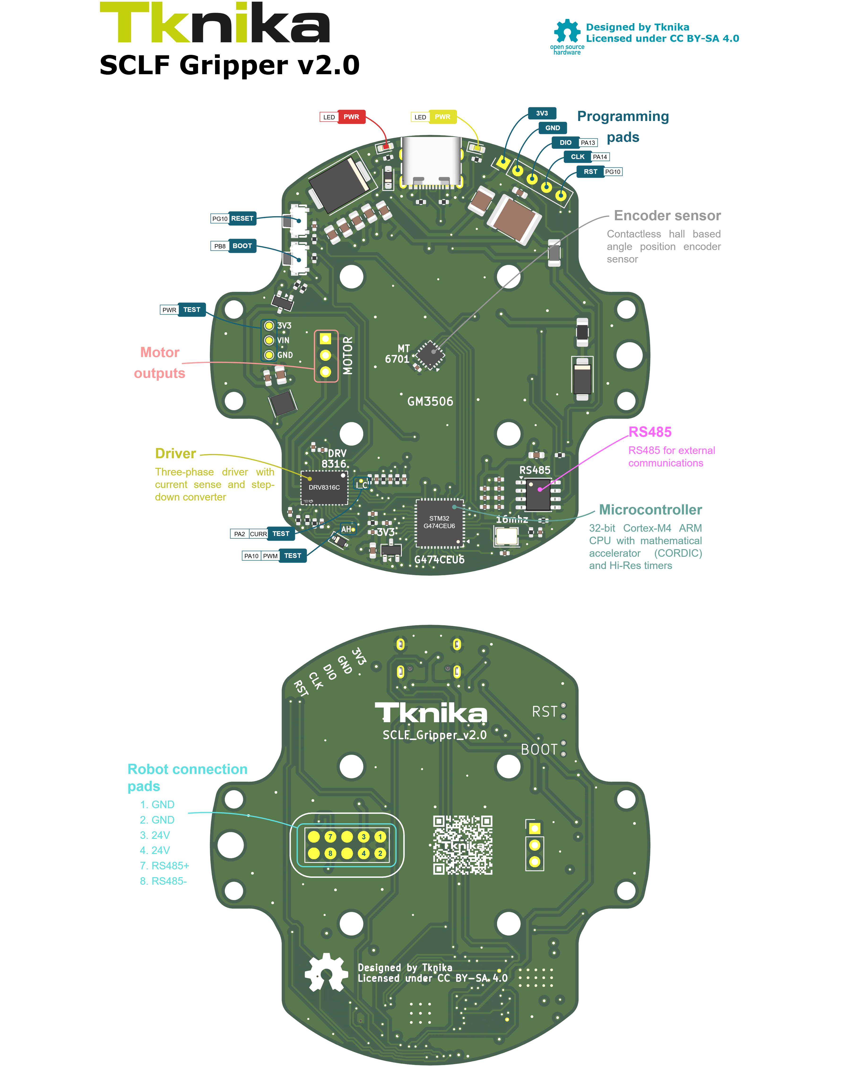
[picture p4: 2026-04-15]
images/Infography.png

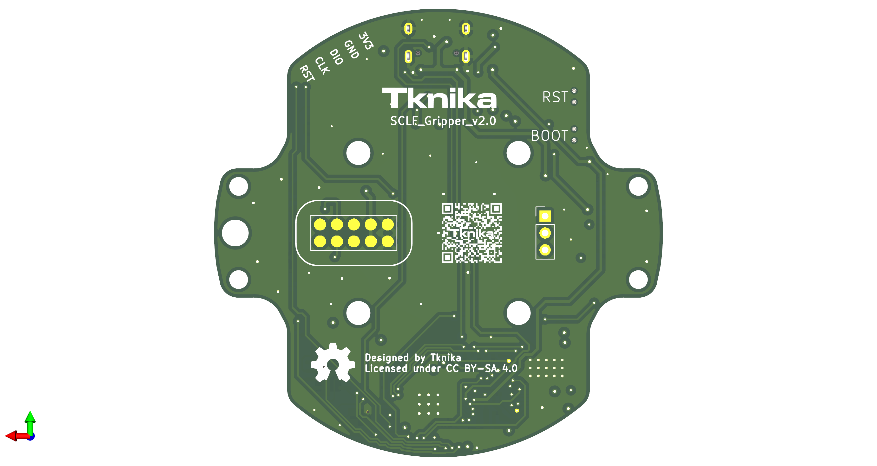
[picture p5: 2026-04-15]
images/Gripper_Bottom.png

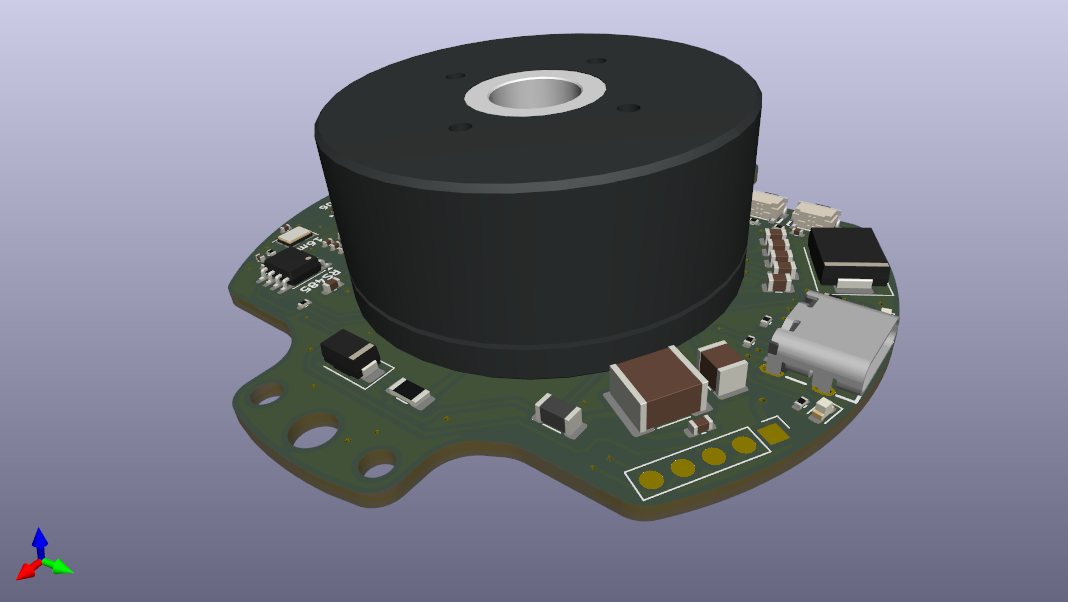
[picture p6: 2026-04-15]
images/Gripper_Motor2.png

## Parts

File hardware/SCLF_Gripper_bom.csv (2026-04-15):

Reference | Qty | Value | DNP | Exclude from BOM | Exclude from Board | Footprint | Datasheet
C1 | 1 | 10uF-50V |  |  |  | Capacitor_SMD:C_1210_3225Metric | https://www.lcsc.com/datasheet/C53084458.pdf
C2 | 1 | 22uF-50V |  |  |  | Capacitor_SMD:C_2220_5750Metric | https://www.lcsc.com/datasheet/C784103.pdf
C3,C13 | 2 | 100nF |  |  |  | Capacitor_SMD:C_0603_1608Metric | https://www.lcsc.com/datasheet/C14663.pdf,~
C23,C25,C26,C37,C40,C41 | 6 | 1uF |  |  |  | Capacitor_SMD:C_0402_1005Metric | https://www.lcsc.com/datasheet/C52923.pdf,~
C27,C30,C34,C36,C38,C42,C43,C47,C48 | 9 | 100nF |  |  |  | Capacitor_SMD:C_0402_1005Metric | https://www.lcsc.com/datasheet/C307331.pdf,~
C28,C29 | 2 | 10pF |  |  |  | Capacitor_SMD:C_0402_1005Metric | https://www.lcsc.com/datasheet/C32949.pdf,~
C31,C32,C33 | 3 | 22pF |  |  |  | Capacitor_SMD:C_0402_1005Metric | https://www.lcsc.com/datasheet/C1555.pdf,~
C35,C54 | 2 | 22uF |  |  |  | Capacitor_SMD:C_0603_1608Metric | https://www.lcsc.com/datasheet/C59461.pdf,~
C44,C45,C46,C52,C56,C57 | 6 | 10uF |  |  |  | Capacitor_SMD:C_0805_2012Metric | https://www.lcsc.com/datasheet/C440198.pdf,~
D1 | 1 | BZT52B5V1S |  |  |  | Diode_SMD:D_SOD-323 | https://www.lcsc.com/datasheet/C19077434.pdf
D2,D4 | 2 | LED |  |  |  | LED_SMD:LED_0603_1608Metric | https://www.lcsc.com/datasheet/C2286.pdf,~
D3 | 1 | 1N4148WS |  |  |  | Diode_SMD:D_SOD-323_HandSoldering | https://www.lcsc.com/datasheet/C2128.pdf
D5 | 1 | SMAJ33CA |  |  |  | Diode_SMD:D_SMA | https://www.lcsc.com/datasheet/C19077549.pdf
D6 | 1 | D_Schottky |  |  |  | Diode_SMD:D_SMC | https://www.lcsc.com/datasheet/C908690.pdf
J1 | 1 | Conn_01x05 |  | Excluido del BOM |  | Aimar:PogoPinPads_1x05_P2.54mm | ~
J2 | 1 | Conn_01x03 |  | Excluido del BOM |  | Connector_PinHeader_2.54mm:PinHeader_1x03_P2.54mm_Vertical | ~
J3 | 1 | Coupling_02x05_Odd_Even |  | Excluido del BOM |  | Aimar:Coupling_Conn_2x05_P2.54mm | ~
L1 | 1 | 47uH |  |  |  | Inductor_SMD:L_Changjiang_FTC303015D | https://www.lcsc.com/datasheet/C96151.pdf
L2 | 1 | BLM31PG330SN1 |  |  |  | Inductor_SMD:L_1206_3216Metric | https://www.lcsc.com/datasheet/C74090.pdf
Q1 | 1 | AO3401A |  |  |  | Package_TO_SOT_SMD:SOT-23 | https://www.lcsc.com/datasheet/C15127.pdf
R2,R3,R16,R25 | 4 | 5,1k |  |  |  | Resistor_SMD:R_0402_1005Metric | https://www.lcsc.com/datasheet/C25905.pdf,~
R9,R21,R28,R32 | 4 | 10k |  |  |  | Resistor_SMD:R_0402_1005Metric | https://www.lcsc.com/datasheet/C25744.pdf,~
R10 | 1 | 120 |  |  |  | Resistor_SMD:R_0402_1005Metric | https://www.lcsc.com/datasheet/C25079.pdf
R17,R22,R23,R24,R26,R31,R33 | 7 | 330 |  |  |  | Resistor_SMD:R_0402_1005Metric | https://www.lcsc.com/datasheet/C25104.pdf,~
R19,R20 | 2 | 100k |  |  |  | Resistor_SMD:R_0402_1005Metric | https://www.lcsc.com/datasheet/C25741.pdf,~
SW1,SW2 | 2 | TSA002A3512A02 |  |  |  | USB:SW-SMD_BZCN_TSA002A35XXX | https://www.lcsc.com/datasheet/C2888932.pdf
U1 | 1 | DRV8316CRRGFR |  |  |  | USB:VQFN-40_L7.0-W5.0-P0.50-BL-EP5.7 | https://www.lcsc.com/datasheet/C5447274.pdf
U4 | 1 | MAX3485 |  |  |  | Package_SO:SOIC-8_3.9x4.9mm_P1.27mm | https://www.lcsc.com/datasheet/C8963.pdf
U8 | 1 | MT6701QT |  |  |  | Package_DFN_QFN:QFN-16-1EP_3x3mm_P0.5mm_EP1.7x1.7mm | https://www.lcsc.com/datasheet/C2913974.pdf
U9 | 1 | STM32G474CEU6 |  |  |  | Package_DFN_QFN:QFN-48-1EP_7x7mm_P0.5mm_EP5.6x5.6mm | https://www.lcsc.com/datasheet/C1235412.pdf
U10 | 1 | XC6206P332MR |  |  |  | Package_TO_SOT_SMD:SOT-23-3 | https://www.lcsc.com/datasheet/C5446.pdf
USB1 | 1 | TYPE-C 16PIN 2MD(073) |  |  |  | USB:USB-C-SMD_TYPE-C-6PIN-2MD-073 | https://www.lcsc.com/datasheet/C2765186.pdf
X1 | 1 | Crystal_GND24 |  |  |  | Crystal:Crystal_SMD_Abracon_ABM8AIG-4Pin_3.2x2.5mm | https://www.lcsc.com/datasheet/C1669787.pdf

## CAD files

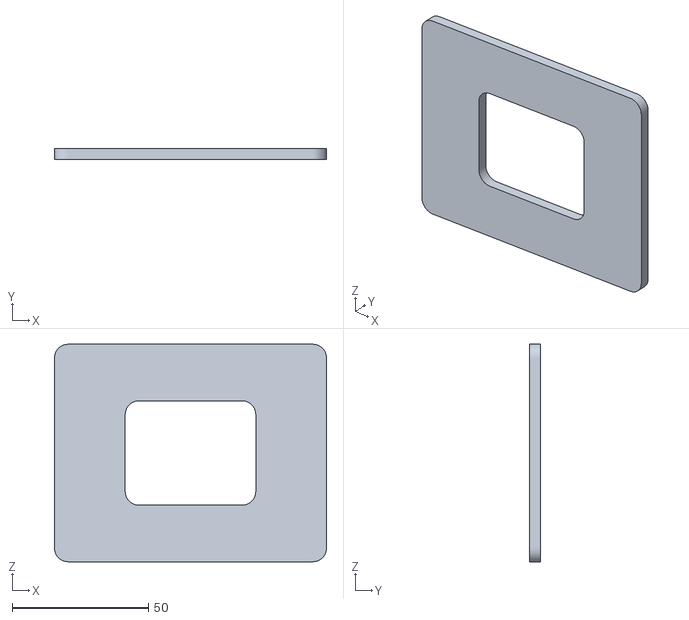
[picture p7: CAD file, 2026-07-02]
hardware/test_bench/cad/Test_Bench_Base.stl
100.0 x 4.00 x 80.0

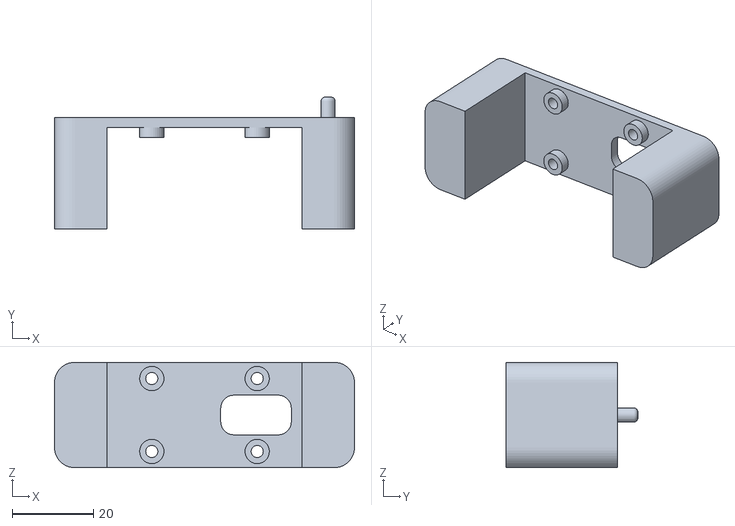
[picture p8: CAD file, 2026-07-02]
hardware/test_bench/cad/Test_Bench_Bench.stl
74.0 x 32.5 x 26.0

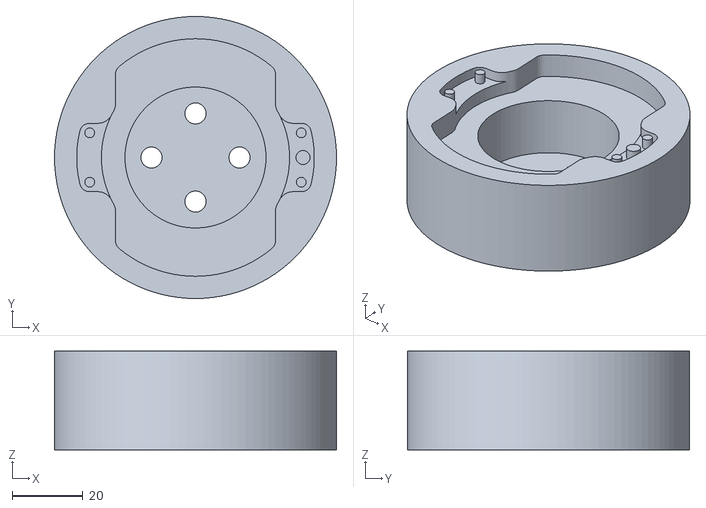
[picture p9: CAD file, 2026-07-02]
hardware/test_bench/cad/Motor_Mounting.stl
80.0 x 80.0 x 28.0

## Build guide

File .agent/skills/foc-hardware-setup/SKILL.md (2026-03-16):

---
name: foc-hardware-setup
description: Analiza el archivo DRV-uC_connections.md para extraer el pinout de un microcontrolador STM32 y un driver de potencia para Simple FOC. Úsalo antes de escribir código de hardware para ahorrar tiempo y tokens.
---

# Configuración de Hardware FOC

Cuando se te pida configurar el hardware o mapear los pines, sigue estrictamente estos pasos:

## Paso 1: Lectura de Planos
- Lee el archivo `hardware/DRV-uC_connections.md` que contiene una tabla resumida con el mapeo exacto de pines.
- NO intentes leer los archivos `.kicad_sch` o `.kicad_pcb` de la carpeta `/hardware/` ya que consumen demasiados tokens y no son necesarios si existe este resumen.
- Rastrea las conexiones indicadas en ese archivo desde el MCU hasta el driver de potencia (ej. DRV8316) y el sensor de posición (ej. MT6701).

## Paso 2: Creación del Artefacto
- Genera una tabla en Markdown detallando: Pin del MCU, Función (PWM A/B/C, SPI, I2C, Current Sense) y Periférico/Timer interno del STM32.
- **Advertencia:** Asegúrate de asignar Timers avanzados a los pines PWM.

## Paso 3: Aprobación
- Detente y pide al usuario que revise y apruebe la tabla de pines generada.
- NO escribas código en `src/main.cpp` hasta recibir la confirmación explícita del usuario.

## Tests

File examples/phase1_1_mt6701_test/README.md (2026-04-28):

# Fase 1.1: MT6701 Sentsorearen Testa (Standalone)

Adibide honen helburua MT6701 sentsore magnetikoa (encoder-a) SPI bidez irakurtzea da, angelu absolutua eta metatua (birak kontatuz) lortzeko. **Test honetan motorra eta driverra (DRV8316) erabat ezgaituta daude segurtasunagatik.**

## Prestaketa

1. Ziurtatu Gripper plaka elikatuta dagoela eta sentsorea konektatuta dagoela.
2. Konpilatu eta kargatu firmwarea ingurune espezifikoa erabiliz:
   ```bash
   pio run -e test_mt6701 --target upload
   ```

## Programaren funtzionamendua

* **Angelu Metatua (`Cumulative Angle`):** Programak birak zenbatzen ditu. Ardatzari buelta bat baino gehiago ematen badiozu, angelua 360º-tik gora igotzen joango da (edo negatiboa bihurtu kontrako noranzkoan).
* **Zero Posizioa:** Programa abiaraztean (edo reset sakatzean), dagoen posizioa "0" bezala hartzen da erreferentzia gisa.
* **Serie-Portua:** Datuak 500ms-ro inprimatzen dira `Serial` bidez.

## Nola Probatu

1. Ireki Serie-Monitorea (pio device monitor --baud 115200).
2. Eskuz mugitu motorraren ardatza.
3. Pantailan hiru balore agertuko dira:
   - `>Angle_Abs_Deg`: Angelu absolutua (0-360º).
   - `>Angle_Cum_Deg`: Angelu metatua (birak kontuan hartuta).
   - `>Raw_Counts`: Sentsorearen balore gordina (0 - 16383).

---

# Fase 1.1: Test del Sensor MT6701 (Standalone) [ES]

El objetivo de este ejemplo es validar la lectura del encoder magnético MT6701 vía SPI, obteniendo tanto el ángulo absoluto como el acumulado (contando vueltas). **El motor y el driver (DRV8316) están desactivados por seguridad.**

## Cómo Funciona el Programa

1.  **Inicialización a Cero**: Al arrancar el programa o presionar el botón de RESET, la posición actual del imán se define como el punto **0 grados**.
2.  **Seguimiento de Vueltas**: El programa llama a `sensor.update()` en cada ciclo para detectar cuándo el imán completa una vuelta. Esto permite calcular el **Angulo Acumulado**.
3.  **Salida de Datos**: Cada 500ms se envían por el puerto serie los siguientes datos para visualizar en el *Serial Plotter* o *Teleplot*:
    *   `Angle_Abs_Deg`: Ángulo actual dentro de una vuelta (0-360º).
    *   `Angle_Cum_Deg`: Ángulo total recorrido (ej: 720º si ha dado dos vueltas).
    *   `Raw_Counts`: Valor bruto del sensor (14 bits).

## Instrucciones de Uso

1.  Compila y carga el código usando el entorno específico:
    ```bash
    pio run -e test_mt6701 --target upload
    ```
2.  Abre el monitor serie (pio device monitor --baud 115200).
3.  Gira el eje manualmente y observa cómo `Angle_Cum_Deg` aumenta o disminuye continuamente sin saltos de 360 a 0.

---

# Phase 1.1: MT6701 Sensor Test (Standalone) [EN]

The goal of this example is to validate the reading of the MT6701 magnetic encoder via SPI, obtaining both the absolute and cumulative angle (counting turns). **The motor and driver (DRV8316) are completely disabled for safety.**

## How the Program Works

1.  **Zero Initialization**: When the program starts or the RESET button is pressed, the current magnet position is defined as the **0 degrees** point.
2.  **Turn Tracking**: The program calls `sensor.update()` in each cycle to detect when the magnet completes a turn. This allows calculating the **Cumulative Angle**.
3.  **Data Output**: Every 500ms, the following data is sent through the serial port for visualization in the *Serial Plotter* or *Teleplot*:
    *   `Angle_Abs_Deg`: Current angle within one turn (0-360º).
    *   `Angle_Cum_Deg`: Total angle traveled (e.g., 720º if it has turned twice).
    *   `Raw_Counts`: Raw sensor value (14 bits).

## Usage Instructions

1.  Compile and upload the code using the specific environment:
    ```bash
    pio run -e test_mt6701 --target upload
    ```
2.  Open the serial monitor (pio device monitor --baud 115200).
3.  Rotate the axis manually and observe how `Angle_Cum_Deg` increases or decreases continuously without 360 to 0 jumps.

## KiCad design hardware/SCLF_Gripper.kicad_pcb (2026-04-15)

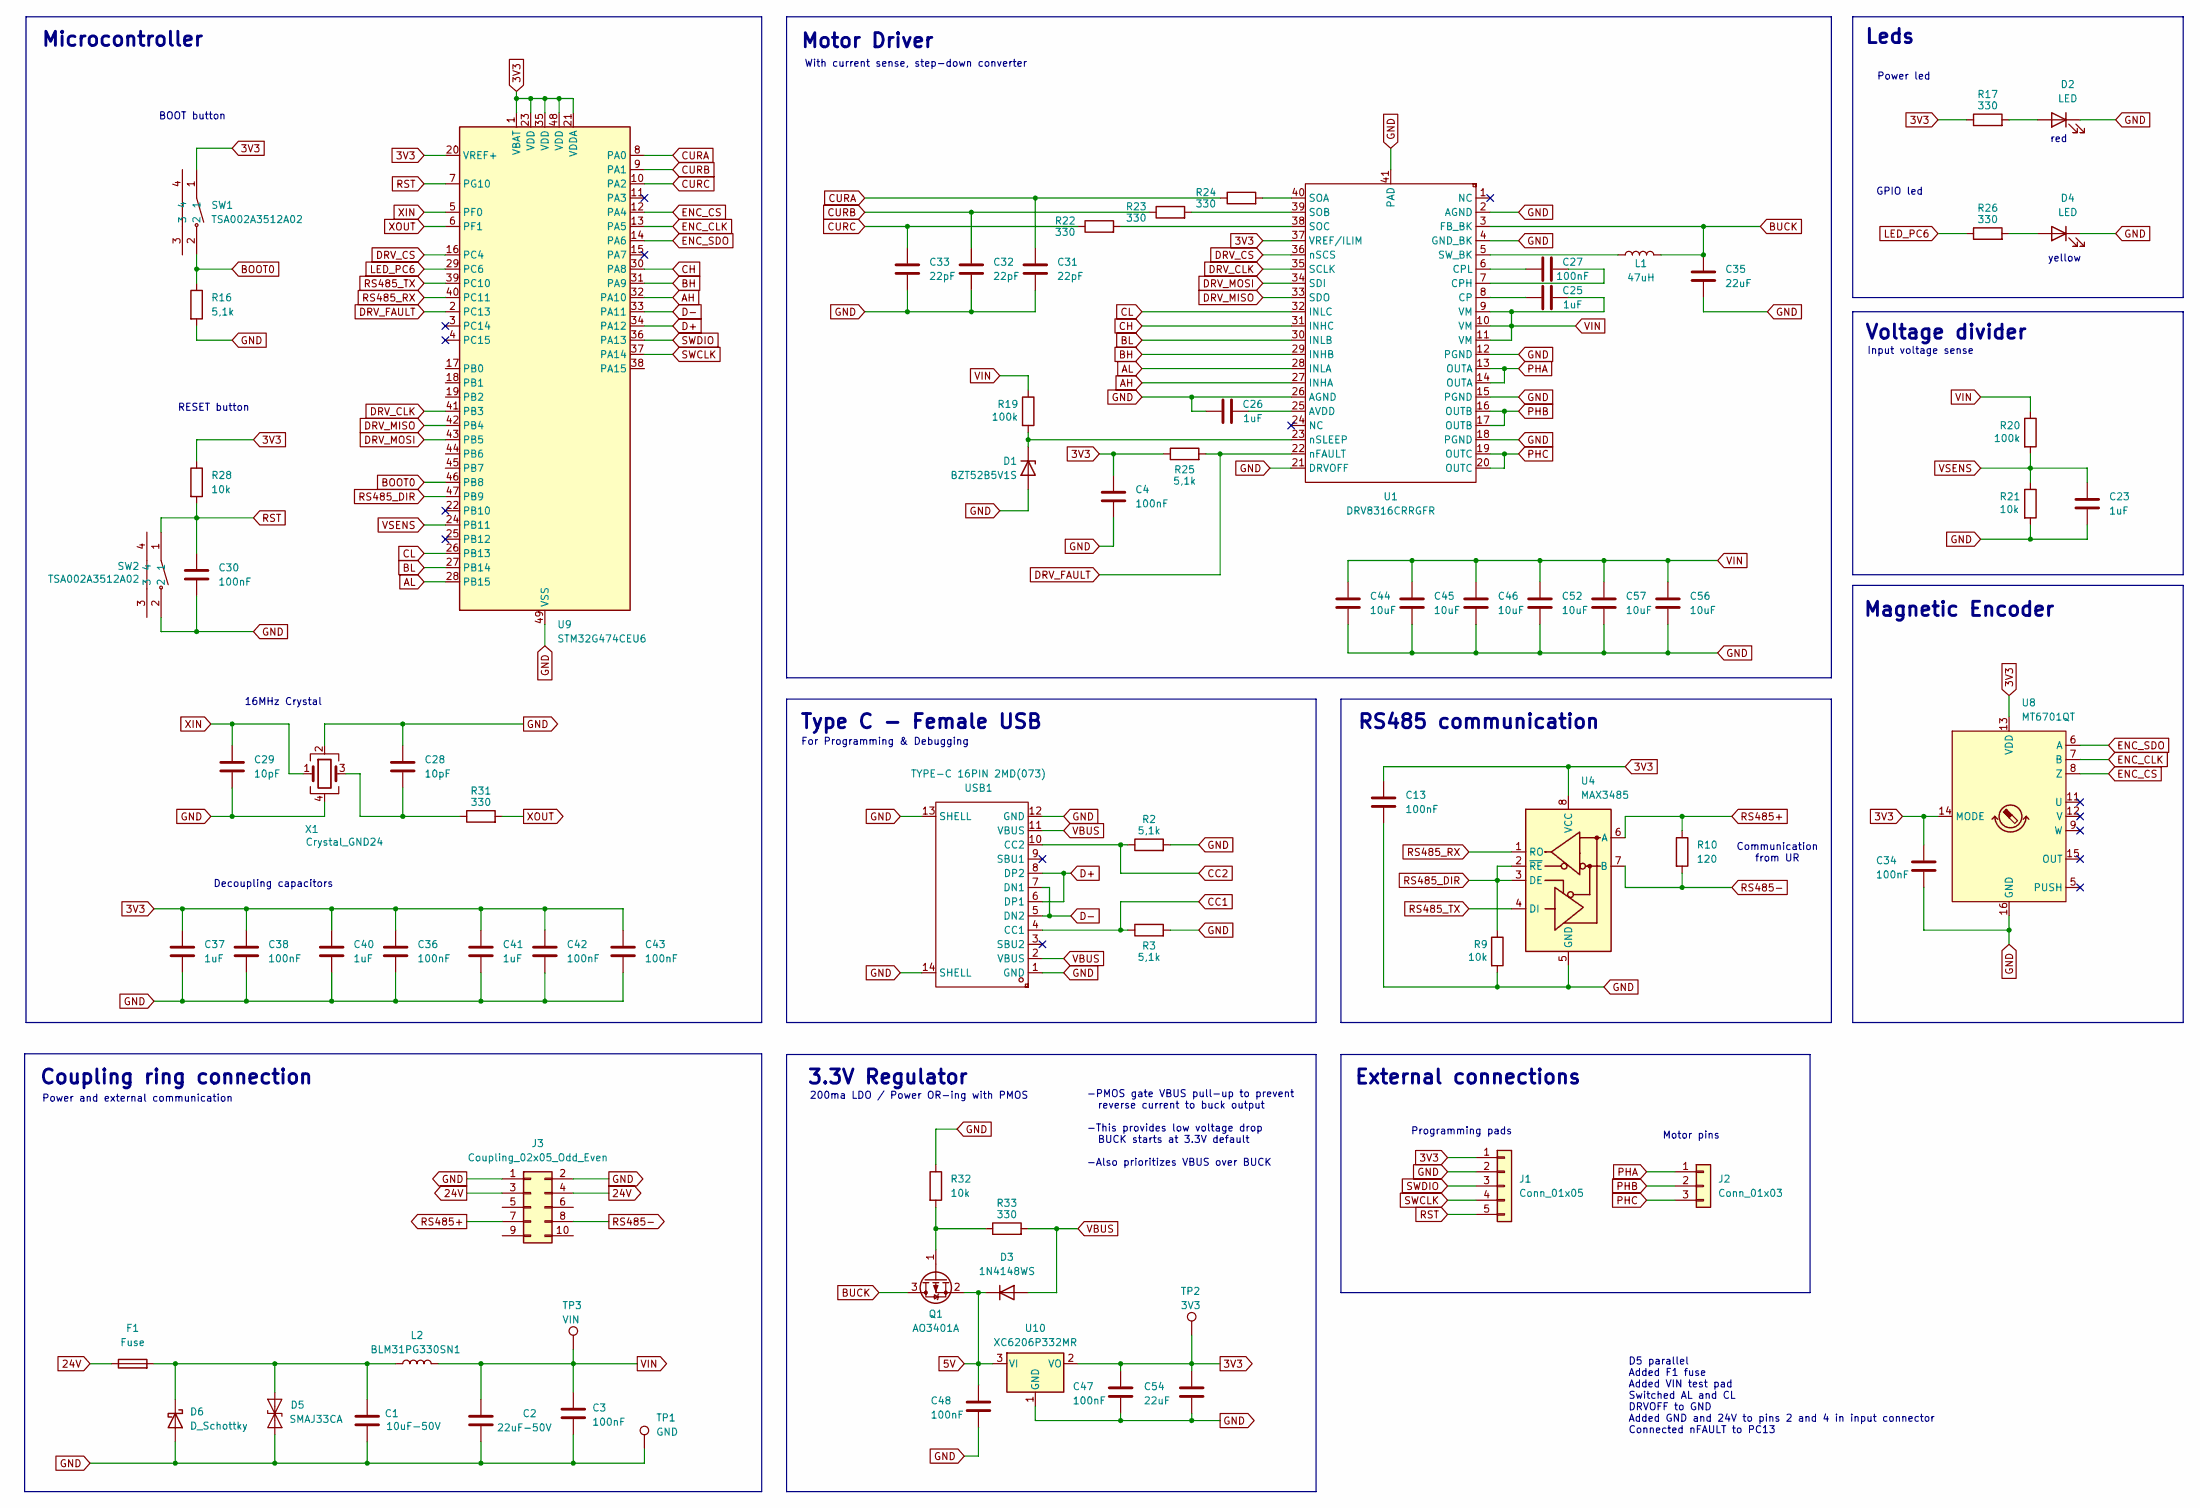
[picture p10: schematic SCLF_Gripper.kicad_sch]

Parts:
C1: 10uF-50V; C_1210_3225Metric; LCSC Part C53084458
C2: 22uF-50V; C_2220_5750Metric; LCSC Part C784103
C3, C13: 100nF; C_0603_1608Metric; LCSC Part C14663
C4, C27, C30, C34, C36, C38, C42, C43, C47, C48: 100nF; C_0402_1005Metric; LCSC Part C307331
C23, C25, C26, C37, C40, C41: 1uF; C_0402_1005Metric; LCSC Part C52923
C28, C29: 10pF; C_0402_1005Metric; LCSC Part C32949
C31, C32, C33: 22pF; C_0402_1005Metric; LCSC Part C1555
C35, C54: 22uF; C_0603_1608Metric; LCSC Part C59461
C44, C45, C46, C52, C56, C57: 10uF; C_0805_2012Metric; LCSC Part C440198
D1: BZT52B5V1S; D_SOD-323; LCSC Part C19077434
D2: LED; LED_0603_1608Metric; LCSC Part C2286
D3: 1N4148WS; D_SOD-323_HandSoldering; LCSC Part C2128
D4: LED; LED_0603_1608Metric; LCSC Part C72038
D5: SMAJ33CA; D_SMA; LCSC Part C19077549
D6: D_Schottky; D_SMC; LCSC Part C908690
F1: Fuse; Fuse_1206_3216Metric_Pad1.42x1.75mm_HandSolder; LCSC Part C41342
J1: Conn_01x05; PogoPinPads_1x05_P2.54mm
J2: Conn_01x03; PinHeader_1x03_P2.54mm_Vertical_Center
J3: Coupling_02x05_Odd_Even; Coupling_Conn_2x05_P2.54mm
L1: 47uH; L_Changjiang_FTC303015D; LCSC Part C96151
L2: BLM31PG330SN1; L_1206_3216Metric; LCSC Part C74090
Q1: AO3401A; SOT-23; LCSC Part C15127
R2, R3, R16, R25: 5,1k; R_0402_1005Metric; LCSC Part C25905
R9, R21, R28, R32: 10k; R_0402_1005Metric; LCSC Part C25744
R10: 120; R_0402_1005Metric; LCSC Part C25079
R17, R22, R23, R24, R26, R31, R33: 330; R_0402_1005Metric; LCSC Part C25104
R19, R20: 100k; R_0402_1005Metric; LCSC Part C25741
SW1, SW2: TSA002A3512A02; SW-SMD_BZCN_TSA002A35XXX; LCSC Part C2888932
TP1: GND; TestPoint_Pad_D1.0mm
TP2: 3V3; TestPoint_Pad_D1.0mm
TP3: VIN; TestPoint_Pad_D1.0mm
U1: DRV8316CRRGFR; VQFN-40_L7.0-W5.0-P0.50-BL-EP5.7; LCSC Part C5447274
U4: MAX3485; SOIC-8_3.9x4.9mm_P1.27mm; LCSC Part C8963
U8: MT6701QT; QFN-16-1EP_3x3mm_P0.5mm_EP1.7x1.7mm; LCSC Part C2913974
U9: STM32G474CEU6; QFN-48-1EP_7x7mm_P0.5mm_EP5.6x5.6mm; LCSC Part C1235412
U10: XC6206P332MR; SOT-23-3; LCSC Part C5446
USB1: TYPE-C 16PIN 2MD(073); USB-C-SMD_TYPE-C-6PIN-2MD-073; LCSC Part C2765186
X1: Crystal_GND24; Crystal_SMD_Abracon_ABM8AIG-4Pin_3.2x2.5mm; LCSC Part C1669787

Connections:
3V3: C4.1, C13.1, C34.1, C36.1, C37.1, C38.1, C40.1, C41.1, C42.1, C43.1, C47.1, C54.1, J1.1, R17.1, R25.1, R28.1, SW1.1, TP2.1, U1.37 (VREF/ILIM), U4.8 (VCC), U8.13 (VDD), U8.14 (MODE), U9.1 (VBAT), U9.20 (VREF+), U9.21 (VDDA), U9.23 (VDD), U9.35 (VDD), U9.48 (VDD), U10.2 (VO)
5V: C48.1, D3.1 (K), Q1.2 (S), U10.3 (VI)
24V: F1.1, J3.3, J3.4
AH: U1.27 (INHA), U9.32 (PA10)
AL: U1.28 (INLA), U9.28 (PB15)
BH: U1.29 (INHB), U9.31 (PA9)
BL: U1.30 (INLB), U9.27 (PB14)
BOOT0: R16.1, SW1.2, U9.46 (PB8)
BUCK: C35.1, L1.2, Q1.3 (D), U1.3 (FB_BK)
CC1: R3.1, USB1.4 (CC1)
CC2: R2.1, USB1.10 (CC2)
CH: U1.31 (INHC), U9.30 (PA8)
CL: U1.32 (INLC), U9.26 (PB13)
CURA: C31.1, R24.1, U9.8 (PA0)
CURB: C32.1, R23.1, U9.9 (PA1)
CURC: C33.1, R22.1, U9.10 (PA2)
D+: U9.34 (PA12), USB1.6 (DP1), USB1.8 (DP2)
D-: U9.33 (PA11), USB1.5 (DN2), USB1.7 (DN1)
DRV_CLK: U1.35 (SCLK), U9.41 (PB3)
DRV_CS: U1.36 (nSCS), U9.16 (PC4)
DRV_FAULT: R25.2, U1.22 (nFAULT), U9.2 (PC13)
DRV_MISO: U1.33 (SDO), U9.42 (PB4)
DRV_MOSI: U1.34 (SDI), U9.43 (PB5)
ENC_CLK: U8.7 (B), U9.13 (PA5)
ENC_CS: U8.8 (Z), U9.12 (PA4)
ENC_SDO: U8.6 (A), U9.14 (PA6)
GND: C1.2, C2.2, C3.2, C4.2, C13.2, C23.2, C26.1, C28.1, C29.2, C30.2, C31.2, C32.2, C33.2, C34.2, C35.2, C36.2, C37.2, C38.2, C40.2, C41.2, C42.2, C43.2, C44.2, C45.2, C46.2, C47.2, C48.2, C52.2, C54.2, C56.2, C57.2, D1.2 (A), D2.1 (K), D4.1 (K), D5.2 (A2), D6.2 (A), J1.2, J3.1, J3.2, R2.2, R3.2, R9.2, R16.2, R21.2, R32.1, SW2.2, TP1.1, U1.2 (AGND), U1.4 (GND_BK), U1.12 (PGND), U1.15 (PGND), U1.18 (PGND), U1.21 (DRVOFF), U1.26 (AGND), U1.41 (PAD), U4.5 (GND), U8.16 (GND), U8.17 (GND), U9.49 (VSS), U10.1 (GND), USB1.1 (GND), USB1.12 (GND), USB1.13 (SHELL), USB1.14 (SHELL), X1.2, X1.4
LED_PC6: R26.1, U9.29 (PC6)
unnamed: C28.2, R31.1, X1.3
unnamed: D1.1 (K), R19.2, U1.23 (nSLEEP)
unnamed: D2.2 (A), R17.2
unnamed: D4.2 (A), R26.2
unnamed: C1.1, D5.1 (A1), D6.1 (K), F1.2, L2.1
unnamed: Q1.1 (G), R32.2, R33.1
unnamed: C26.2, U1.25 (AVDD)
unnamed: C25.1, U1.8 (CP)
unnamed: C27.2, U1.7 (CPH)
unnamed: C27.1, U1.6 (CPL)
unnamed: R24.2, U1.40 (SOA)
unnamed: R23.2, U1.39 (SOB)
unnamed: R22.2, U1.38 (SOC)
unnamed: L1.1, U1.5 (SW_BK)
PHA: J2.1, U1.13 (OUTA), U1.14 (OUTA)
PHB: J2.2, U1.16 (OUTB), U1.17 (OUTB)
PHC: J2.3, U1.19 (OUTC), U1.20 (OUTC)
RS485+: J3.7, R10.1, U4.6 (A)
RS485-: J3.8, R10.2, U4.7 (B)
RS485_DIR: R9.1, U4.2 (~RE), U4.3 (DE), U9.47 (PB9)
RS485_RX: U4.1 (RO), U9.40 (PC11)
RS485_TX: U4.4 (DI), U9.39 (PC10)
RST: C30.1, J1.5, R28.2, SW2.1, U9.7 (PG10)
SWCLK: J1.4, U9.37 (PA14)
SWDIO: J1.3, U9.36 (PA13)
VBUS: D3.2 (A), R33.2, USB1.2 (VBUS), USB1.11 (VBUS)
VIN: C2.1, C3.1, C25.2, C44.1, C45.1, C46.1, C52.1, C56.1, C57.1, L2.2, R19.1, R20.1, TP3.1, U1.9 (VM), U1.10 (VM), U1.11 (VM)
VSENS: C23.1, R20.2, R21.1, U9.24 (PB11)
XIN: C29.1, U9.5 (PF0), X1.1
XOUT: R31.2, U9.6 (PF1)

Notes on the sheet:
Communication from UR
Leds
red
For Programming & Debugging
16MHz Crystal
Motor pins
200ma LDO / Power OR-ing with PMOS
BOOT button
yellow
Decoupling capacitors
-PMOS gate VBUS pull-up to prevent reverse current to buck output -This provides low voltage drop BUCK starts at 3.3V default -Also prioritizes VBUS over BUCK
With current sense, step-down converter
Motor Driver
External connections
3.3V Regulator
Magnetic Encoder
Microcontroller
Power led
RS485 communication
RESET button
Coupling ring connection
Input voltage sense
D5 parallel Added F1 fuse Added VIN test pad Switched AL and CL DRVOFF to GND Added GND and 24V to pins 2 and 4 in input connector Connected nFAULT to PC13
Power and external communication
GPIO led
Voltage divider
Programming pads
Type C - Female USB

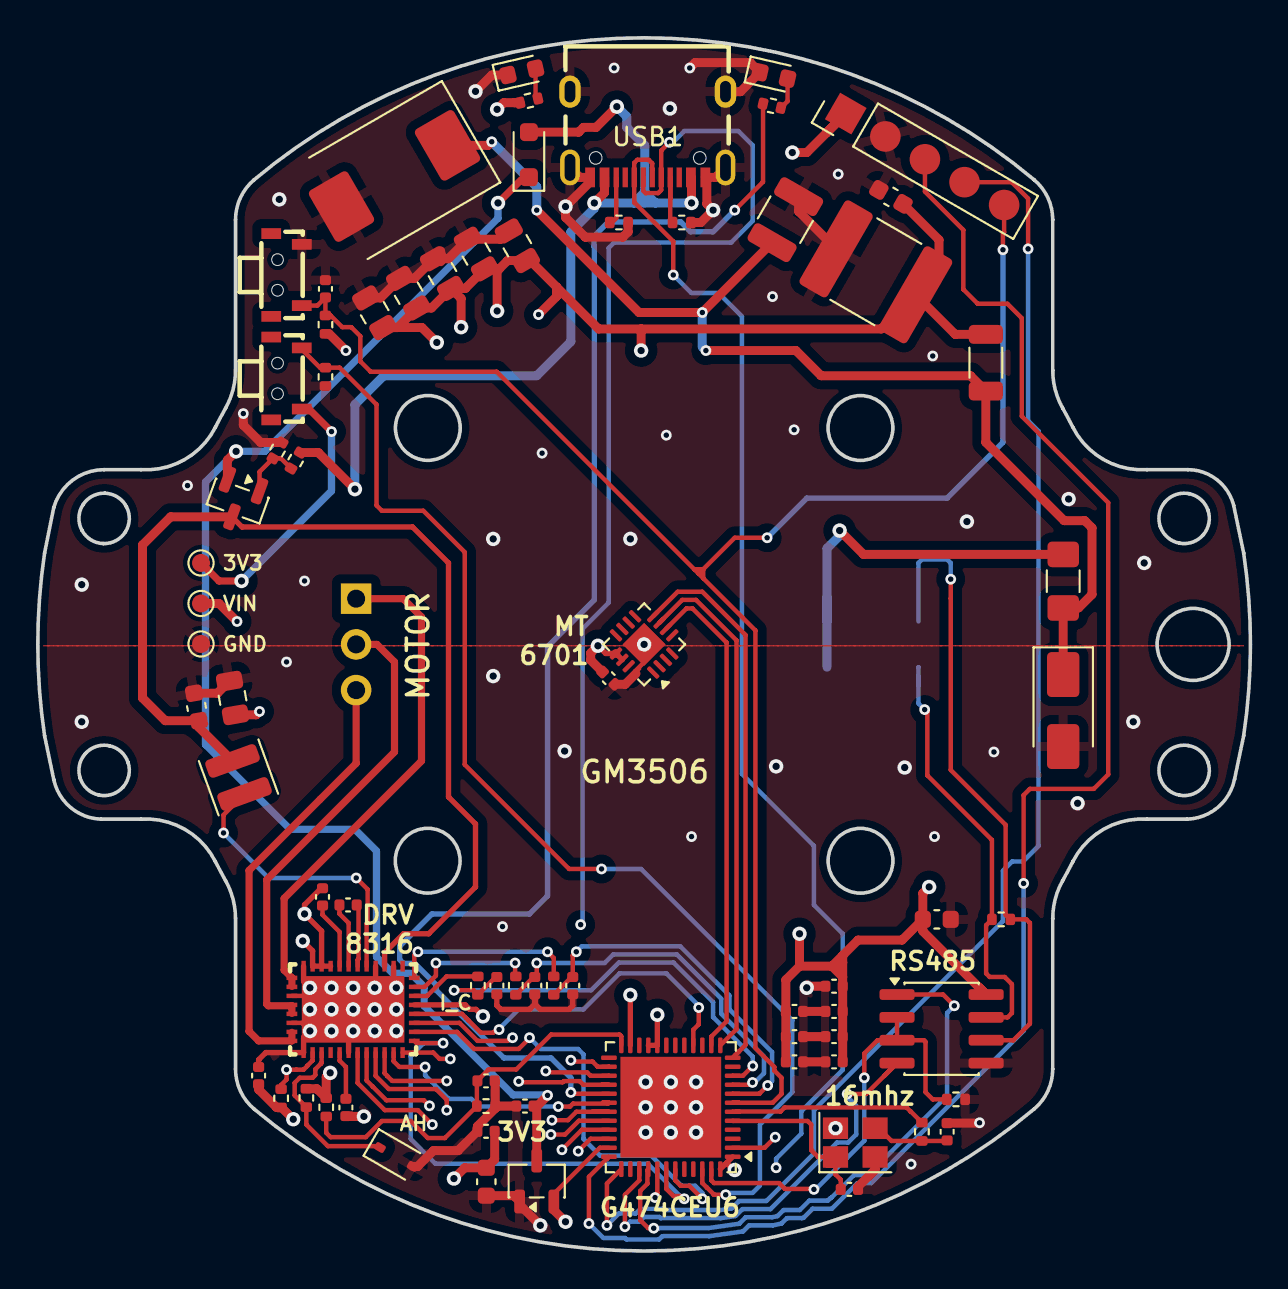
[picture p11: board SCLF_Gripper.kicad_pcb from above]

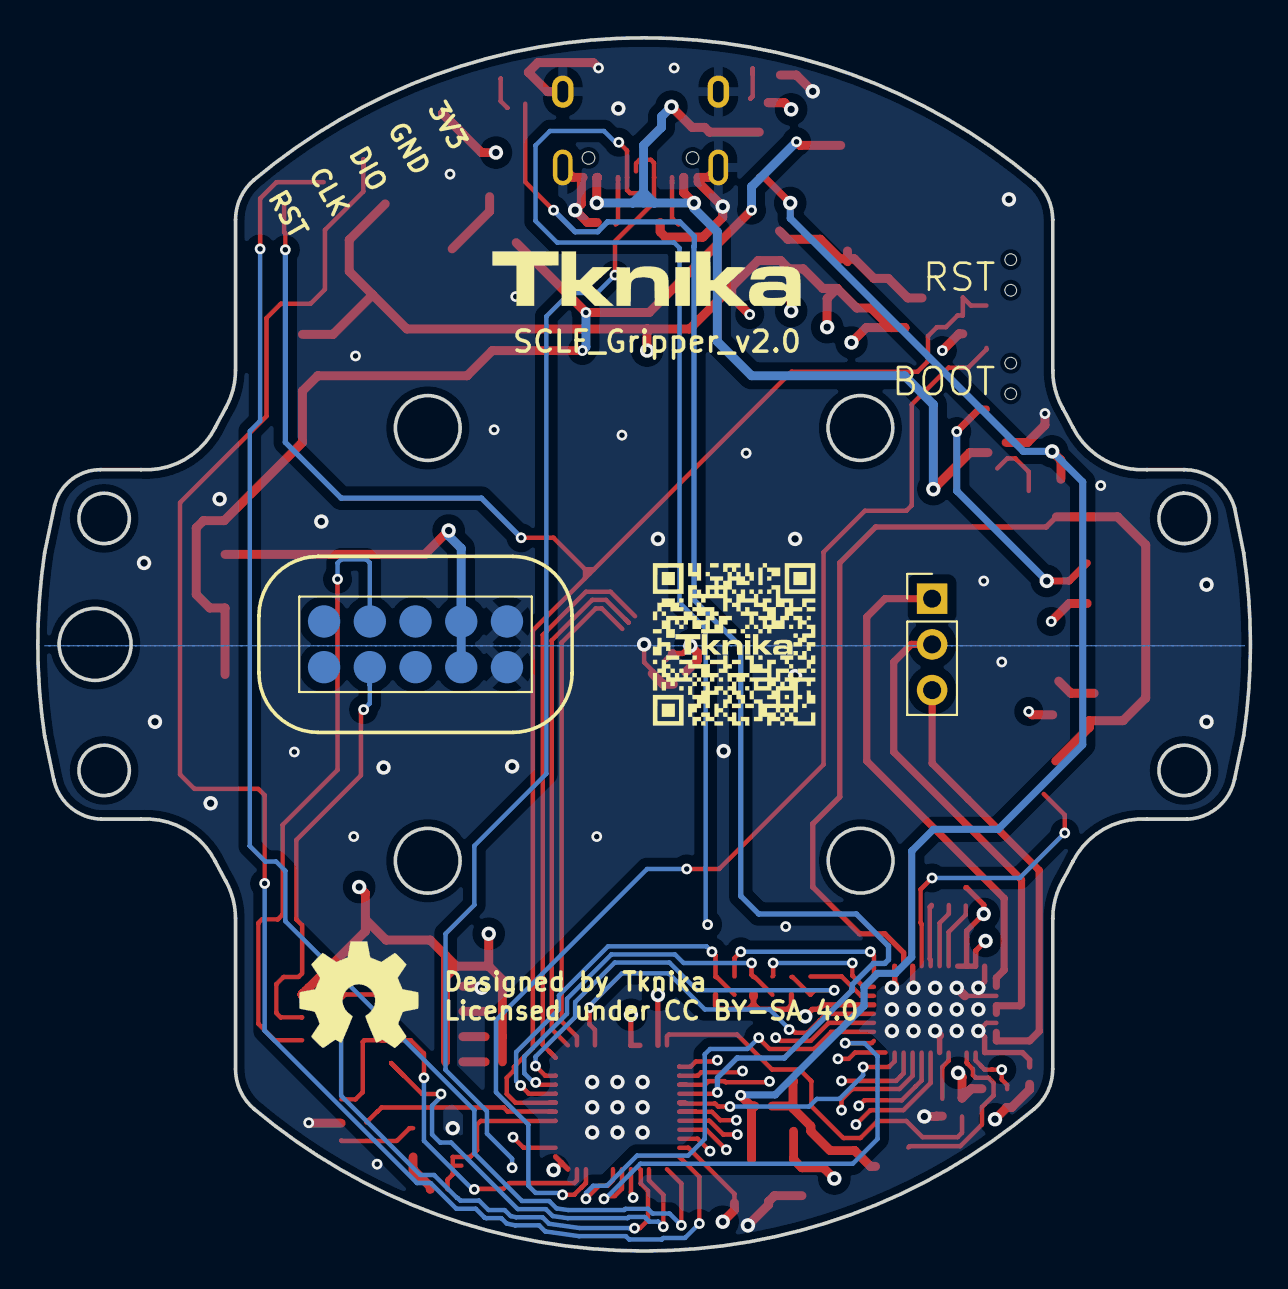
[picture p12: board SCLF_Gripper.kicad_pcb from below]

Board: 4 copper layers, 67.4 x 67.4 mm, 77 parts (3 on the bottom side), 58 nets.

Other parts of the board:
G: LOGO; QR

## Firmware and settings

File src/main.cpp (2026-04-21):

/**
 * SCLF Gripper v1.0 — Phase 4.2: Full RS485 Protocol Test (STABLE)
 * Board:     STM32G474CEU6
 *
 * Objetivo:  Validar comunicación RS485 usando HSE (16MHz Crystal) para 
 *            máxima precisión en el baudrate y bajando a 9600 para test.
 */

#include "comms/RS485.h"
#include "config/pins.h"
#include <Arduino.h>

// --- Erlojuaren Konfigurazioa (16MHz-eko kristala erabiltzeko) ---
extern "C" void SystemClock_Config(void) {
  RCC_OscInitTypeDef RCC_OscInitStruct = {0};
  RCC_ClkInitTypeDef RCC_ClkInitStruct = {0};

  HAL_PWREx_ControlVoltageScaling(PWR_REGULATOR_VOLTAGE_SCALE1_BOOST);

  RCC_OscInitStruct.OscillatorType = RCC_OSCILLATORTYPE_HSI|RCC_OSCILLATORTYPE_HSI48;
  RCC_OscInitStruct.HSIState = RCC_HSI_ON;
  RCC_OscInitStruct.HSICalibrationValue = RCC_HSICALIBRATION_DEFAULT;
  RCC_OscInitStruct.HSI48State = RCC_HSI48_ON;
  RCC_OscInitStruct.PLL.PLLState = RCC_PLL_ON;
  RCC_OscInitStruct.PLL.PLLSource = RCC_PLLSOURCE_HSI;
  RCC_OscInitStruct.PLL.PLLM = RCC_PLLM_DIV4;
  RCC_OscInitStruct.PLL.PLLN = 85;
  RCC_OscInitStruct.PLL.PLLP = RCC_PLLP_DIV2;
  RCC_OscInitStruct.PLL.PLLQ = RCC_PLLQ_DIV2;
  RCC_OscInitStruct.PLL.PLLR = RCC_PLLR_DIV2;
  if (HAL_RCC_OscConfig(&RCC_OscInitStruct) != HAL_OK) { /* Error */ }

  RCC_ClkInitStruct.ClockType = RCC_CLOCKTYPE_HCLK|RCC_CLOCKTYPE_SYSCLK
                              |RCC_CLOCKTYPE_PCLK1|RCC_CLOCKTYPE_PCLK2;
  RCC_ClkInitStruct.SYSCLKSource = RCC_SYSCLKSOURCE_PLLCLK;
  RCC_ClkInitStruct.AHBCLKDivider = RCC_SYSCLK_DIV1;
  RCC_ClkInitStruct.APB1CLKDivider = RCC_HCLK_DIV1;
  RCC_ClkInitStruct.APB2CLKDivider = RCC_HCLK_DIV1;

  if (HAL_RCC_ClockConfig(&RCC_ClkInitStruct, FLASH_LATENCY_4) != HAL_OK) { /* Error */ }
}

// --- Estatua eta Instantziak ---
struct GripperState {
    float angle = 1.23f;
    bool enabled = false;
} state;

RS485 comms;

void setup() {
    Serial.begin(9600); // Sincronizado con RS-485 para evitar confusiones
    uint32_t t = millis();
    while (!Serial && (millis() - t) < 2000) {}

    // Segurtasuna: Irteerak itxi
    pinMode(PIN_AH, OUTPUT); digitalWrite(PIN_AH, LOW);
    pinMode(PIN_BH, OUTPUT); digitalWrite(PIN_BH, LOW);
    pinMode(PIN_CH, OUTPUT); digitalWrite(PIN_CH, LOW);
    pinMode(PIN_DRV_CS, OUTPUT); digitalWrite(PIN_DRV_CS, HIGH);
    pinMode(PIN_ENC_CS, OUTPUT); digitalWrite(PIN_ENC_CS, HIGH);
    pinMode(PIN_LED, OUTPUT);

    // RS485 Hasieratu: 9600 BAUD (Egonkortasunagatik)
    comms.begin(1, 9600);
    
    Serial.println("\n\n========================================");
    Serial.println("  SCLF Gripper v1.0 — Phase 4.2 (STABLE)");
    Serial.println("  RS485 Bus Speed: 9600 Baud");
    Serial.println("========================================");
}

void processFrame(const RS485Frame& frame) {
    if (!frame.valid || !comms.isForMe(frame)) return;

    Serial.print("[RS485 Rx] ID:");
    Serial.print(frame.deviceId);
    Serial.print(" CMD:");
    Serial.print(frame.cmd);
    Serial.print(" VAL:");
    Serial.println(frame.value);

    if (strcmp(frame.cmd, "?A") == 0) {
        comms.reply("A", state.angle);
        Serial.print("[VCP Tx] Reply: 1:A:"); Serial.println(state.angle);
    } else if (strcmp(frame.cmd, "EN") == 0) {
        state.enabled = true;
        comms.send("1:EN:1\n");
        Serial.println("[VCP Tx] Reply: 1:EN:1");
    } else if (strcmp(frame.cmd, "PING") == 0) {
        comms.send("1:PONG:0\n");
        Serial.println("[VCP Tx] Reply: 1:PONG:0");
    } else {
        char buf[64];
        snprintf(buf, sizeof(buf), "1:ACK_%s:%s\n", frame.cmd, frame.value);
        comms.send(buf);
        Serial.print("[VCP Tx] Reply: "); Serial.print(buf);
    }
}

void loop() {
    RS485Frame frame;
    bool frameReceived = false;

    if (comms.update(frame)) frameReceived = true;
    
    while (Serial.available()) {
        char c = Serial.read();
        char buf[2] = {c, '\0'};
        if (comms.simulateRx(buf, frame)) {
            frameReceived = true;
            break;
        }
    }

    if (frameReceived) {
        processFrame(frame);
    }

    static uint32_t last_led = 0;
    if (millis() - last_led >= 500) {
        digitalWrite(PIN_LED, !digitalRead(PIN_LED));
        last_led = millis();
    }
}

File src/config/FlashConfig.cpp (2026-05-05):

#include "config/FlashConfig.h"
#include "motor/MotorController.h"
#include <stm32g4xx_hal.h>

FlashConfig::FlashConfig() {
    resetToDefaults();
}

void FlashConfig::resetToDefaults() {
    _currentConfig.magic = 0x5C1F; // "SCLF"
    _currentConfig.version = 1;
    _currentConfig.rs485_id = 1;
    _currentConfig.zero_electric_angle = 0.0f;
    // CRÍTICO: sensor_direction = 0 = Direction::UNKNOWN.
    // Fuerza la calibración completa en el próximo arranque.
    _currentConfig.sensor_direction = 0;
    _currentConfig.vel_kp = 0.5f;
    _currentConfig.vel_ki = 5.0f;
    _currentConfig.vel_kd = 0.0f;
    _currentConfig.pos_kp = 20.0f;
    _currentConfig.voltage_limit = 8.0f;  // Suficiente para mover el motor
    _currentConfig.current_limit = 2.0f;
    _currentConfig.velocity_limit = 20.0f;
    _currentConfig.crc = 0;
}

bool FlashConfig::load() {
    DeviceConfig temp;
    memcpy(&temp, (void*)FLASH_ADDR, sizeof(DeviceConfig));

    if (temp.magic != 0x5C1F) return false;

    uint32_t computedCrc = calculateCRC(temp);
    if (computedCrc != temp.crc) return false;

    _currentConfig = temp;
    return true;
}

bool FlashConfig::save(const DeviceConfig& config) {
    DeviceConfig toSave = config;
    toSave.crc = calculateCRC(toSave);

    HAL_FLASH_Unlock();

    // 1. Borrar la página
    FLASH_EraseInitTypeDef eraseInit;
    eraseInit.TypeErase = FLASH_TYPEERASE_PAGES;
    eraseInit.Banks = FLASH_BANK_1; 
    eraseInit.Page = (FLASH_ADDR - 0x08000000) / FLASH_PAGE_SIZE;
    eraseInit.NbPages = 1;

    uint32_t pageError = 0;
    if (HAL_FLASHEx_Erase(&eraseInit, &pageError) != HAL_OK) {
        uint32_t err = HAL_FLASH_GetError();
        Serial.print("[FLASH] Erase Error: ");
        Serial.println(err);
        HAL_FLASH_Lock();
        return false;
    }

    // 2. Escribir los datos (DoubleWord = 64 bits = 8 bytes)
    uint64_t* dataPtr = (uint64_t*)&toSave;
    uint32_t addr = FLASH_ADDR;
    uint32_t iterations = sizeof(DeviceConfig) / 8;
    if (sizeof(DeviceConfig) % 8 != 0) iterations++;

    for (uint32_t i = 0; i < iterations; i++) {
        if (HAL_FLASH_Program(FLASH_TYPEPROGRAM_DOUBLEWORD, addr, dataPtr[i]) != HAL_OK) {
            uint32_t err = HAL_FLASH_GetError();
            Serial.print("[FLASH] Write Error at ");
            Serial.print(addr, HEX);
            Serial.print(": ");
            Serial.println(err);
            HAL_FLASH_Lock();
            return false;
        }
        addr += 8;
    }

    HAL_FLASH_Lock();
    _currentConfig = toSave;
    return true;
}

uint32_t FlashConfig::calculateCRC(const DeviceConfig& config) {
    uint32_t crc = 0;
    uint32_t* ptr = (uint32_t*)&config;
    uint32_t len = (sizeof(DeviceConfig) - sizeof(uint32_t)) / 4;

    for (uint32_t i = 0; i < len; i++) {
        crc ^= ptr[i];
    }
    return crc;
}

void FlashConfig::applyTo(MotorController& mc) {
    BLDCMotor& motor = mc.getMotor();

    // Parámetros de calibración eléctrica
    motor.zero_electric_angle = _currentConfig.zero_electric_angle;
    motor.sensor_direction = (Direction)_currentConfig.sensor_direction;

    // Ganancias PID (sintonizables en tiempo de ejecución)
    motor.PID_velocity.P = _currentConfig.vel_kp;
    motor.PID_velocity.I = _currentConfig.vel_ki;
    motor.PID_velocity.D = _currentConfig.vel_kd;
    motor.P_angle.P      = _currentConfig.pos_kp;

    // NOTA: NO se aplican voltage_limit / velocity_limit desde Flash.
    // Esos límites de seguridad los gestiona MotorController::_configureMotor()
    // y deben ser invariantes respecto a la Flash.
}

void FlashConfig::updateFrom(MotorController& mc) {
    BLDCMotor& motor = mc.getMotor();
    
    _currentConfig.zero_electric_angle = motor.zero_electric_angle;
    _currentConfig.sensor_direction = (int32_t)motor.sensor_direction;
    
    _currentConfig.vel_kp = motor.PID_velocity.P;
    _currentConfig.vel_ki = motor.PID_velocity.I;
    _currentConfig.vel_kd = motor.PID_velocity.D;
    
    _currentConfig.pos_kp = motor.P_angle.P;
    
    _currentConfig.voltage_limit = motor.voltage_limit;
    _currentConfig.current_limit = motor.current_limit;
    _currentConfig.velocity_limit = motor.velocity_limit;
}

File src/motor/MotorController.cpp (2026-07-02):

#include <Arduino.h>
#include "motor/MotorController.h"

MotorController::MotorController()
    : _encoder(),
      _motor(11), // GM3506 (11 pole pairs)
      _driver(PIN_CH, PIN_CL, PIN_BH, PIN_BL, PIN_AH, PIN_AL),
      // SPI dedicado en PB5(MOSI), PB4(MISO), PB3(SCK) — nunca toca PA5/PA6
      _spi_drv(PIN_DRV_MOSI, PIN_DRV_MISO, PIN_DRV_CLK),
      _current_sense(_drv) {
}

bool MotorController::begin() {
    _initHardware();
    _configureMotor();

    // 1. Inicializar el driver del chip DRV8316
    // Usar instancia SPI dedicada (PB3/PB4/PB5) para no interferir con
    // el bit-banging del encoder MT6701 en PA5/PA6.
    _spi_drv.begin();

    if (!_drv.begin(&_spi_drv)) {
        SimpleFOCDebug::println("MC: DRV8316 Init FAILED");
        return false;
    }
    _drv.setCSAGain(DRV8316_BIT::CSA_GAIN_0V3);
    
    // Asegurar modo 6-PWM y driver habilitado (Control 3: PWM_MODE=00, DRV_OFF=0)
    uint16_t ctrl3 = _drv.readRegister(DRV8316_REG::REG_CONTROL3);
    ctrl3 &= ~0x07; // Limpiar bits 2:0 (DRV_OFF y PWM_MODE)
    _drv.writeRegister(DRV8316_REG::REG_CONTROL3, ctrl3);
    
    _drv.clearFaults();

    // 2. Inicializar encoder (bit-banging)
    if (!_encoder.begin()) {
        SimpleFOCDebug::println("MC: MT6701 Init FAILED");
        // No salimos con error aquí necesariamente, el lazo abierto puede funcionar sin encoder
    }

    // 3. Inicializar Driver SimpleFOC
    _driver.voltage_power_supply = 24.0f;
    _driver.init();
    _motor.linkDriver(&_driver);

    // 3.5 Inicializar sensor de corriente y vincularlo
    _current_sense.getSimpleFOC().linkDriver(&_driver);
    if (!_current_sense.begin()) {
        SimpleFOCDebug::println("MC: CurrentSense Init FAILED");
    } else {
        _motor.linkCurrentSense(&_current_sense.getSimpleFOC());
    }

    // ⚠️ CRÍTICO: Re-forzar GPIO en los pines del encoder DESPUÉS de driver.init().
    // En STM32G474, PA6 = TIM1_BKIN (AF). Al inicializar TIM1 para 6-PWM,
    // STM32duino puede reconfigurarlo como función alternativa, rompiendo
    // el bit-banging del MT6701. pinMode() fuerza el modo GPIO de vuelta.
    pinMode(PIN_ENC_CS,  OUTPUT); digitalWrite(PIN_ENC_CS, HIGH);
    pinMode(PIN_ENC_CLK, OUTPUT); digitalWrite(PIN_ENC_CLK, LOW);
    pinMode(PIN_ENC_SDO, INPUT);

    // 4. Inicializar Motor SimpleFOC
    _motor.linkSensor(&_encoder);
    _motor.init();

    return true;
}

bool MotorController::initFOC() {
    SimpleFOCDebug::println("MC: Initializing FOC...");
    
    _motor.initFOC();
    _motor.enable();

    if (_motor.motor_status == FOCMotorStatus::motor_ready) {
        SimpleFOCDebug::println("MC: FOC Ready!");
        return true;
    } else {
        SimpleFOCDebug::println("MC: FOC Initialization FAILED");
        return false;
    }
}

void MotorController::update() {
    _motor.loopFOC();
    _motor.move();
}

void MotorController::setTarget(float target) {
    _motor.target = target;
}

void MotorController::setMode(MotionControlType mode) {
    _motor.controller = mode;
}

void MotorController::enable(bool en) {
    if (en) _motor.enable();
    else _motor.disable();
}

void MotorController::dumpRegisters() {
    SimpleFOCDebug::println("--- DRV8316 Register Dump ---");
    for (uint8_t i = 0; i <= 0x0B; i++) {
        uint16_t val = _drv.readRegister(i);
        Serial.print("Reg 0x");
        if (i < 0x10) Serial.print("0");
        Serial.print(i, HEX);
        Serial.print(": 0x");
        if (val < 0x100) Serial.print("0");
        if (val < 0x10) Serial.print("0");
        Serial.println(val, HEX);
    }
    
    Serial.print("Motor Status: "); Serial.println((int)_motor.motor_status);
    Serial.print("Sensor Direction: "); Serial.println((int)_motor.sensor_direction);
    Serial.print("Zero Elec Angle: "); Serial.println(_motor.zero_electric_angle, 4);
    SimpleFOCDebug::println("-----------------------------");
}

void MotorController::forceCalibration() {
    _motor.sensor_direction = Direction::UNKNOWN;
    _motor.initFOC();
}

void MotorController::_initHardware() {
    // LED de diagnóstico o pines extra si fuera necesario
    pinMode(PIN_LED, OUTPUT);
}

void MotorController::_configureMotor() {
    // Límites de seguridad ajustados a la fuente de alimentación (1.5A)
    _motor.voltage_limit = 8.0f;
    _driver.voltage_limit = 8.0f;
    _motor.velocity_limit = 20.0f;
    
    // Voltaje de alineación — suficiente para superar fricción y detent torque
    _motor.voltage_sensor_align = 10.0f;

    // ── PIDs — Valores conservadores para primer tuning ─────────────────────
    // GM3506: motor de gimbal, alta reluctancia, sensible a ganancias altas.
    // I=0 hasta encontrar P estable — el windup del integral bloquea el motor.
    _motor.PID_velocity.P  = 0.15f;
    _motor.PID_velocity.I  = 0.0f;   // ← CRÍTICO: I=0 hasta tuning estable
    _motor.PID_velocity.D  = 0.0f;
    _motor.LPF_velocity.Tf = 0.05f;  // Filtro más suave — reduce ruido del encoder

    // Lazo de posición — ajustar solo tras tener velocidad estable
    _motor.P_angle.P       = 5.0f;

    // Modo por defecto: velocidad cerrada con target=0 (no mueve al inicio)
    _motor.controller = MotionControlType::velocity;

}

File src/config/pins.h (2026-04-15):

#pragma once
// ============================================================
//  pins.h — SCLF Gripper Pin Definitions
//  VERIFIED directly from SCLF_Gripper.kicad_sch
//  Single source of truth. Never use magic numbers elsewhere.
//  Board: STM32G474CEU6 | Date: 2026-04-15
// ============================================================

// ─── SWD / Programming pads (managed by debugger) ───────────
// PA13 = SWDIO, PA14 = SWCLK — do NOT reconfigure these as GPIO
// PG10 = RST (also SWD reset)

// ─── Boot & Reset ────────────────────────────────────────────
#define PIN_BOOT        PB8     // BOOT0 button — hold during reset for DFU mode
#define PIN_RESET       PG10    // Hardware reset button

// ─── DRV8316C Gate Driver (SPI — shared bus with PB3/4/5) ───
// nFAULT is routed to PC13. DRVOFF is tied to GND (always enabled).
#define PIN_DRV_FAULT   PC13    // DRV8316 nFAULT — Hardware fault indicator (active low)
#define PIN_DRV_CS      PC4     // DRV8316 nSCS  — SPI Chip Select (active low)
#define PIN_DRV_CLK     PB3     // DRV8316 SCLK  — SPI Clock  (SPI1)
#define PIN_DRV_MISO    PB4     // DRV8316 SDO   — SPI MISO   (SPI1)
#define PIN_DRV_MOSI    PB5     // DRV8316 SDI   — SPI MOSI   (SPI1)

// ─── Motor PWM outputs (DRV8316 INH/INL ← HRTIM/TIM) ───────
// High-side (INHA=PA10, INHB=PA9, INHC=PA8 on DRV8316)
#define PIN_AH          PA10    // Phase A High
#define PIN_BH          PA9     // Phase B High
#define PIN_CH          PA8     // Phase C High
// Low-side (INLA=PB15, INLB=PB14, INLC=PB13 on DRV8316)
#define PIN_AL          PB15    // Phase A Low
#define PIN_BL          PB14    // Phase B Low
#define PIN_CL          PB13    // Phase C Low

// ─── Inline Current Sense ADC (DRV8316 SOA/SOB/SOC) ─────────
#define PIN_CURA        PA0     // Phase A current sense (ADC1_IN1)
#define PIN_CURB        PA1     // Phase B current sense (ADC1_IN2)
#define PIN_CURC        PA2     // Phase C current sense (ADC1_IN3) — also test pad

// ─── Voltage Sense ───────────────────────────────────────────
#define PIN_VSENS       PB11    // DC bus voltage sense (ADC)

// ─── MT6701 Magnetic Encoder (SPI — separate CS) ────────────
// Max SPI clock: 10 MHz. Use SPISettings(5000000, MSBFIRST, SPI_MODE0)
#define PIN_ENC_CS      PA4     // MT6701 ~CS  (active low)
#define PIN_ENC_CLK     PA5     // MT6701 CLK
#define PIN_ENC_SDO     PA6     // MT6701 SDO  (MISO — read only, no MOSI needed)

// ─── RS-485 (MAX3485 — UART3 / half-duplex) ─────────────────
#define PIN_RS485_TX    PC10    // UART TX → MAX3485 DI
#define PIN_RS485_RX    PC11    // UART RX ← MAX3485 RO
#define PIN_RS485_DIR   PB9     // DE/RE control: HIGH=TX, LOW=RX

// ─── USB Virtual COM Port ────────────────────────────────────
// PA11 = USB_DM (D-), PA12 = USB_DP (D+) — fixed hardware, no defines needed

// ─── LED ─────────────────────────────────────────────────────
#define PIN_LED         PC6     // Status LED

// ─── Crystal (16 MHz HSE) ────────────────────────────────────
// PF0 = OSC_IN, PF1 = OSC_OUT — configured as HSE, do NOT use as GPIO

// ─── Reserved (appear in schematic, function unknown) ────────
// PB6, PB7, PA15 — do not assign without schematic review

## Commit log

2026-02-11 Kicad schematic
    [SCLF_Gripper_v1.0.kicad_sch]
2026-02-11 Kicad PCB
    [SCLF_Gripper_v1.0.kicad_pcb]
2026-02-11 Update Gripper_info image link in README
2026-02-25 chore: move hardware files and images to repository structure
    [SCLF_Gripper_v1.0_bom.csv]
2026-02-25 Fix Windows SimpleFOC compilation bugs, paths, and hardware initialization code
    [DRV8316.cpp, DRV8316.h, FaultManager.cpp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]
2026-03-04 docs: Add clarification on DFU bootloader and PA9/VBUS sensing on STM32G4
2026-03-04 feat: Fase 1.2 DRV8316 SPI Test amaituta
2026-03-06 feat: enable USB CDC VCP + custom upload via STM32CubeProgrammer
    - platformio.ini: upload_protocol=custom using STM32CubeProgrammer CLI (bypasses PIO registry timeout)
    - platformio.ini: added -DUSBCON -DUSBD_USE_CDC -DHAL_PCD_MODULE_ENABLED for USB VCP on PA11/PA12
    - src/main.cpp: loaded fase1_1_mt6701_test (MT6701 standalone test, motor disabled)
2026-03-07 docs: Fase 1.4 RS485 loopback terminada + Encoder 3.3V verificado
2026-03-11 Update Fase 1.1 documentation and sensor logic
2026-03-16 chore: optimize foc-hardware-setup skill to read markdown instead of kicad files
2026-03-24 docs: add driver to MCU connections mapping
2026-03-24 hardware: update pin mapping for v2 PCB (swap AL and CL)
    [pins.h]
2026-04-14 Cleanup: Remove v1.0 suffix from hardware files
    [SCLF_Gripper.kicad_pcb, SCLF_Gripper.kicad_sch, SCLF_Gripper_bom.csv]
2026-04-15 docs: update pinout, images to PNG and hardware design files
    [SCLF_Gripper.kicad_pcb, SCLF_Gripper.kicad_sch, SCLF_Gripper_bom.csv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]
2026-04-15 docs: reset documentation and tasks for new prototype validation
    [pins.h]
2026-04-15 docs: complete phase 1.2 drv spi validation on new prototype
2026-04-15 docs: finalize phase 1.3 motor open loop validation on new prototype
2026-04-16 docs: finalize Phase 1.4 RS485 Ping and refine driver
2026-04-16 chore: start phase 1.5 current sense
2026-04-16 feat(phase1.5): finalize current sense validation and fix SPI protocol bug
    [CurrentSense.cpp, CurrentSense.h, DRV8316.cpp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]
2026-04-16 fix: corrigo sintaxis y estructura en el test de open loop (Phase 1.3)
    [main.cpp]
2026-04-19 Phase 2.1: Implement MotorController and Open-Loop FOC test
2026-04-21 fix(encoder): MT6701::update() calls Sensor::update() for correct FOC velocity tracking - doc: update fase2_2 README with test results and speed ramp instructions
    [MT6701.cpp]
2026-04-21 feat: implement full RS485 control protocol with shorthand support and update tasks
    [RS485.cpp, main.cpp]
2026-04-21 chore: fix phase numbering from 4 to 3 in examples and tasks
    [main.cpp]
2026-04-22 Phase 5: Fault Manager implementation validated with mechanical stall test
    [FaultManager.cpp, FaultManager.h, main.cpp]
2026-04-22 Phase 6: Persistence implementation validated with dual-bank fix
    [FlashConfig.cpp, main.cpp]
2026-04-28 WIP: Motor-Encoder alignment and phase 7 infrastructure
2026-05-05 Phase 7.1 Complete: Motor-Encoder Alignment, Advanced Tuning Infrastructure, and Multi-language Documentation Updates
2026-05-05 docs: actualizar MEMORY.md con parámetros PID de fase 7.1
2026-07-02 docs & examples: añadir ejemplo phase3_3 UR RS-485 y actualizar tareas
    [Motor_Mounting.stl, SCLF_Gripper_Test_bench.kicad_pcb, SCLF_Gripper_Test_bench.kicad_sch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]
2026-10-15 docs(assets): reestructurar carpeta images con subdirectorios Logo y Gripper images
2026-10-15 docs: añadir Logo_gripper.jpg en cabecera de READMEs
